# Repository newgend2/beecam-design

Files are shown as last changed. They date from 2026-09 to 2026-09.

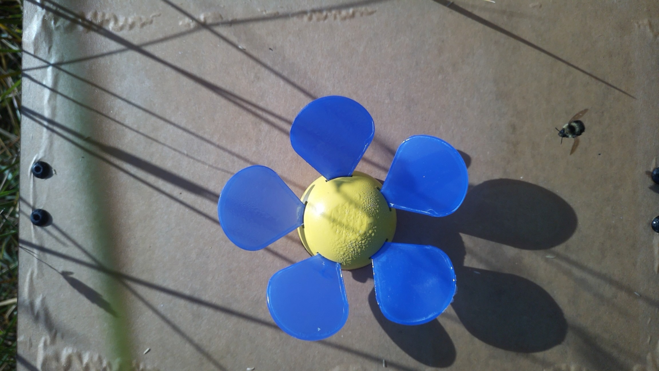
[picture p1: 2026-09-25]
docs/media/flower-prototype.jpg

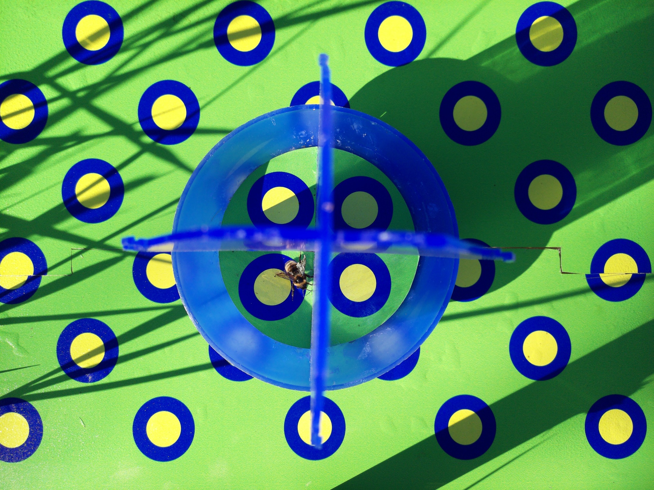
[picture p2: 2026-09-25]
docs/media/camera-visitor.jpg

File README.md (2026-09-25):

# BeeCam design

An open camera-trap assembly explorer with a labelled 3D model, dimensioned
reference drawings, custom acrylic DXFs, printable artwork and a consolidated
parts list. Explore the complete camera or the removable electronics assembly.

**[Assembly explorer](https://newgend2.github.io/beecam-design/)** ·
**[Parts list](https://newgend2.github.io/beecam-design/#materials)** ·
**[Source](https://github.com/newgend2/beecam-design)**

## Release 1.0

The frame uses six 80/20 20-2020 members: **570, 420, 280, 280, 220 and 100 mm**.
Allow saw kerf beyond the 1,870 mm net cut length. The 100 mm support sits beside
the stem with both bottoms flush; the platform crossbar rests on it. Set the
upper arm's height in the stem slot and align the camera lens over the vane.

Use four 14057 brackets, one 14060 bracket and one 20-4167 joining plate.
All black extrusion bolts are **11-5308 M5 × 8 mm**, paired with **14122 T-nuts**.
The per-camera total is **32 of each**: 22 frame, 8 platform and 2 box-to-arm.

The 420 × 300 mm imaging platform has two 3 mm acrylic panels and a Ø91.39 mm
opening for a prebuilt [BanfieldBio blue vane trap](https://www.bluevanetraps.com).
Four 3 mm acrylic stopper inserts sit between the vanes. Print the contrast
artwork on adhesive weatherproof vinyl; centre one complete bullseye on each
stopper. The trap's collection jar and lid are not installed.

The nominal 150 × 150 × 90 mm Zulkit enclosure hangs beneath the arm on a
135 × 170 × 3 mm acrylic mounting plate. The lid faces down, with hinges toward
the stem. Add two Ø22 mm lid ports, located from the internal acrylic plate,
and a centred Ø28 mm side port. Register the internal plate in the lid before
transferring the drilling datums. The enclosure includes its lid, cable gland
and four mounting screws.

## Electronics assembly

The 3 mm internal acrylic plate carries a Raspberry Pi Zero 2 W, Witty Pi 4 Mini,
full-size SparkFun DEV-14459 Qwiic HAT, SSD1306 OLED, Adafruit DS3231 STEMMA QT RTC,
CR1220 cell and Raspberry Pi AI Camera. Five Ø20 mm hook-and-loop pairs attach
the plate to the lid. Black dots are used in the build; the linked white dots
are an alternative.

Brass standoff bodies are 15 mm under the Pi, 20 mm between Pi and Witty Pi at
the end opposite the OLED, 10 mm under the OLED and 10 mm under the RTC.
The Pi and tall Witty supports have 6 mm male threads. Four 5 mm standoffs act
as retaining nuts: two at the OLED end of the Pi and two above Witty Pi.
Six M2.5 × 6 mm screws secure the Pi and RTC standoffs from under the acrylic.
Hardware comes from the HELIFOUNER 242-piece M2.5 kit and Kadrick 660-piece M2 kit.

The camera uses four M2 screws and nuts, with one M2.5 nut and one M2 washer as
spacers at each mounting point. Select M2 screw lengths for secure engagement
through each joint without bottoming out.

The Frienda 2×20 header measures **51 × 5 × 23 mm overall**, with **12 mm male
pins**, **2.54 mm pitch** and approximately **0.6 mm pin thickness**. Its sockets
fit the Pi GPIO pins; the male pins pass through the Qwiic HAT into Witty Pi.
One header is used from an eight-pack.

Two 200 mm JST SH cables connect the HAT to the RTC and OLED. Remove one connector
on the OLED cable and solder the leads left-to-right **black, red, yellow, blue**,
viewed from the screen side with the pin edge at the top. Use the AI Camera's
included 22-pin-to-15-pin ribbon to connect it to the Pi Zero. The microSD card
is 128 GB; its full-size SD adapter is shared setup equipment.

## Power and field mounting

Choose one power configuration per camera:

- **Solar:** Voltaic CORE K-P150-V102, with a 50 W panel, 12 V / 18 Ah battery,
  integrated charge controller and panel bracket. The C304 regulator supplies
  5 V to Witty Pi through USB-C.
- **Portable:** Voltaic V75 USB-A Always On output, connected to Witty Pi by a
  USB-A-to-USB-C cable. Recharge between deployments.

Runtime depends on the camera schedule and operating conditions. Attach the
camera stem to a ground-driven T-post with two locally sourced hose clamps
that fit around both members.

## Model and drawing scope

Acrylic outlines and hole positions follow the design DXFs. Inch-based source
geometry is converted at 25.4 mm/in. Use the DXFs for custom acrylic cutting and
manufacturer specifications for fit-critical checks on purchased parts.
The Witty Pi PCB and 184 component solids use UUGear’s STEP geometry; its
fitted GPIO socket and display colours are added separately. The AI Camera
follows the manufacturer physical specification, with its CSI connector facing
the plate centre. The Pi Zero 2 W follows Raspberry Pi’s mechanical drawing,
including the USB and HDMI positions; its components remain reference geometry.
The 3D model simplifies extrusion slots, castings, enclosure mouldings, other board
components and cable routing. It illustrates assembly; it is not manufacturing
CAD for purchased parts. No blue vane fabrication drawings are provided.

`docs/js/data.js` is the shared source for parts, dimensions and procurement
quantities. Generators produce the SVG drawings and CSV/Markdown downloads.
Native CAD and reference photos remain unchanged in ignored private storage.
To regenerate the Witty mesh, run `scripts/export-witty-mesh.py` with FreeCAD’s
Python and `FREECAD_LIB` set to its library directory; pass the vendor STEP path.
Web assets contain geometry-only DXFs, sanitized artwork and curated photo copies. Original CAD
notices are retained in the normalized exports.

## Field setup panel

The **Field setup** tab (`#field`) introduces the blue vane visual lure, the
earlier flower-shaped prototypes, the non-lethal adaptation, solar-powered field stations, camera images and ArUco
re-sightings. Section links and expandable questions support a short presentation.
Select a photo to enlarge it; use the arrow buttons or left/right keys to move
between photos and Escape to close. The tagged-bee crop retains its original
279 × 272 pixels. The movement example is illustrative, not a study result.

Original photographs remain in ignored private storage. Browser copies in
`docs/media/` have orientation applied and metadata removed, with no retouching
or cropping. The six reviewed copies are recorded by checksum in
`scripts/field-media-manifest.json`; the privacy audit rejects unknown or changed
raster files and metadata-bearing headers. New photo copies require the same
review before updating that manifest.

## Preview

```sh
python3 -m http.server 8767 --directory docs --bind 127.0.0.1
```

Open http://127.0.0.1:8767/. All runtime dependencies are vendored; after download,
the viewer requires no CDN, account or backend. ES modules require HTTP serving.

## Regenerate and check

```sh
# When source geometry changes (requires ezdxf):
python3 scripts/import-platform.py /path/to/source-folder
python3 scripts/import-enclosure.py /path/to/source-folder
node scripts/generate-drawings.mjs
node scripts/generate-platform-drawings.mjs
node scripts/generate-enclosure-drawings.mjs
node scripts/generate-electronics-drawings.mjs
node scripts/generate-materials.mjs
node scripts/version-assets.mjs
node scripts/version-assets.mjs --check
node tests/data-checks.mjs
node tests/enclosure-checks.mjs
node tests/electronics-checks.mjs
node tests/materials-checks.mjs
python3 scripts/audit-public.py
```

Regenerate outputs after changing the shared data. Asset versioning stamps the
entry point and application-module imports to prevent mixed cached versions.
Browser checks cover assembly selection, lid motion, isolation, drawings,
parts-list search, repository-subpath URLs and responsive layouts. The
`tests/stopper-occlusion.mjs` rendering check protects the side-view sticker fit.

Publish only `docs/` from the `main` branch using GitHub Pages. Inspect staged
files and check the complete site before publishing. Keep `private/`, original
photos, machine-specific notes and credentials out of Git.

## Sources and reuse

Product sources are linked from the viewer and parts list. The geometry source
manifest is `docs/downloads/electronics-sources.json`. Board references include
Raspberry Pi mechanical drawings, UUGear Witty Pi STEP, SparkFun DEV-14459 Eagle
files and Adafruit DS3231 Eagle/STEP files. Header dimensions come from the
[Frienda listing diagram](https://www.amazon.com/dp/B084Q4W1PW).

Original viewer code and original reference drawings use the MIT license.
Three.js 0.180.0 is vendored under its MIT license in
`docs/vendor/THREE-LICENSE.txt`. Product names, trademarks and manufacturer CAD
remain their owners'. Design geometry and artwork retain original third-party
notices; the viewer code license does not relicense commercial trap designs.

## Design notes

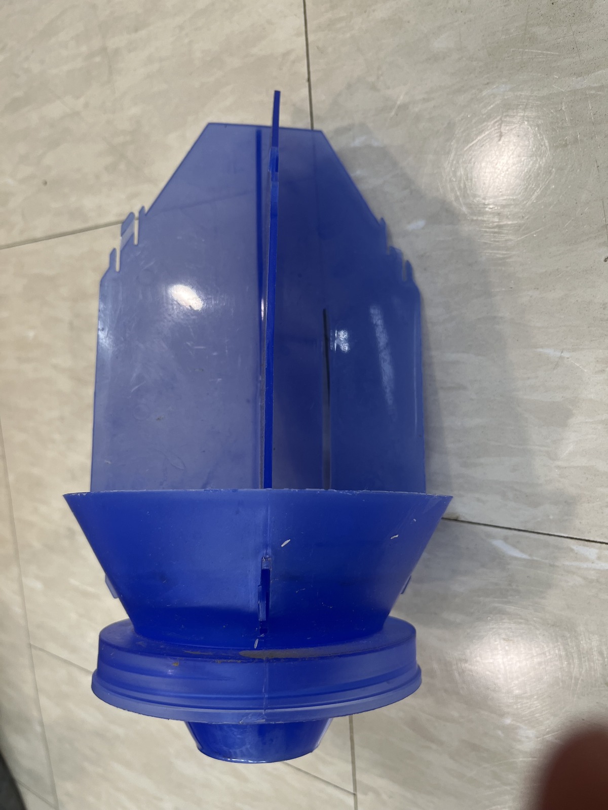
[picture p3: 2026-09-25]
docs/media/blue-vane.jpg

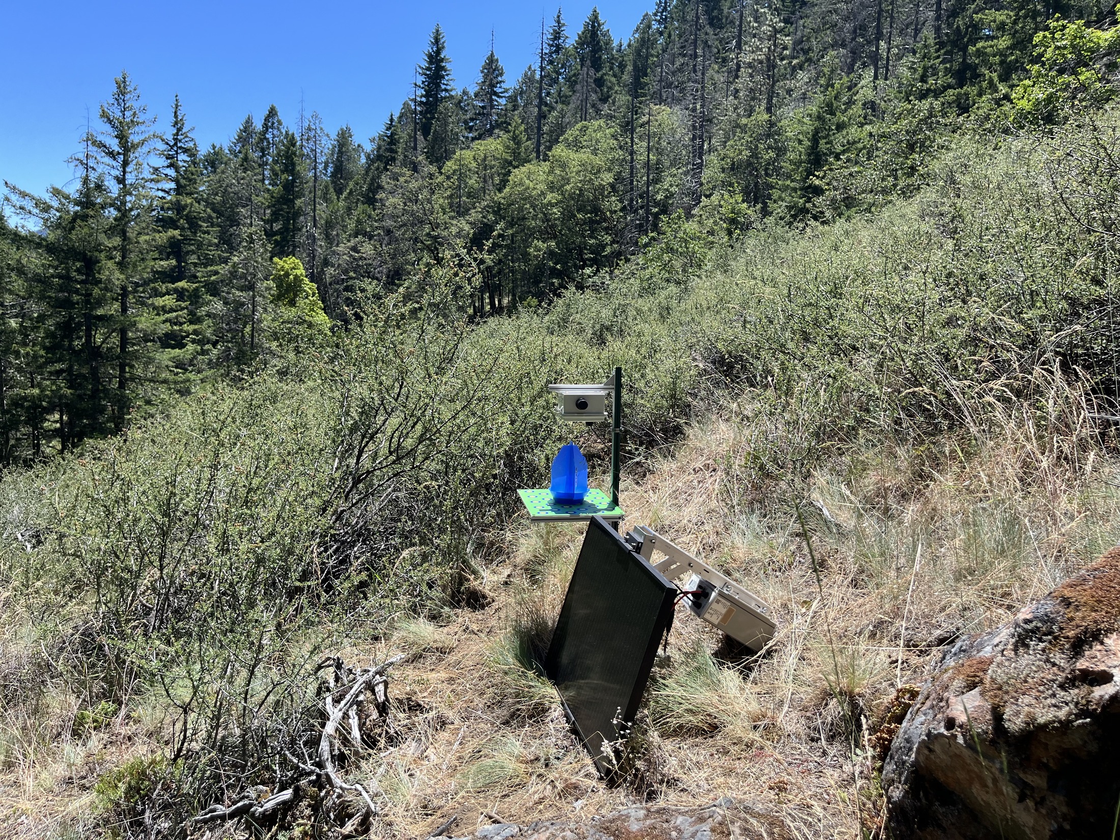
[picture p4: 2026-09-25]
docs/media/field-solar.jpg

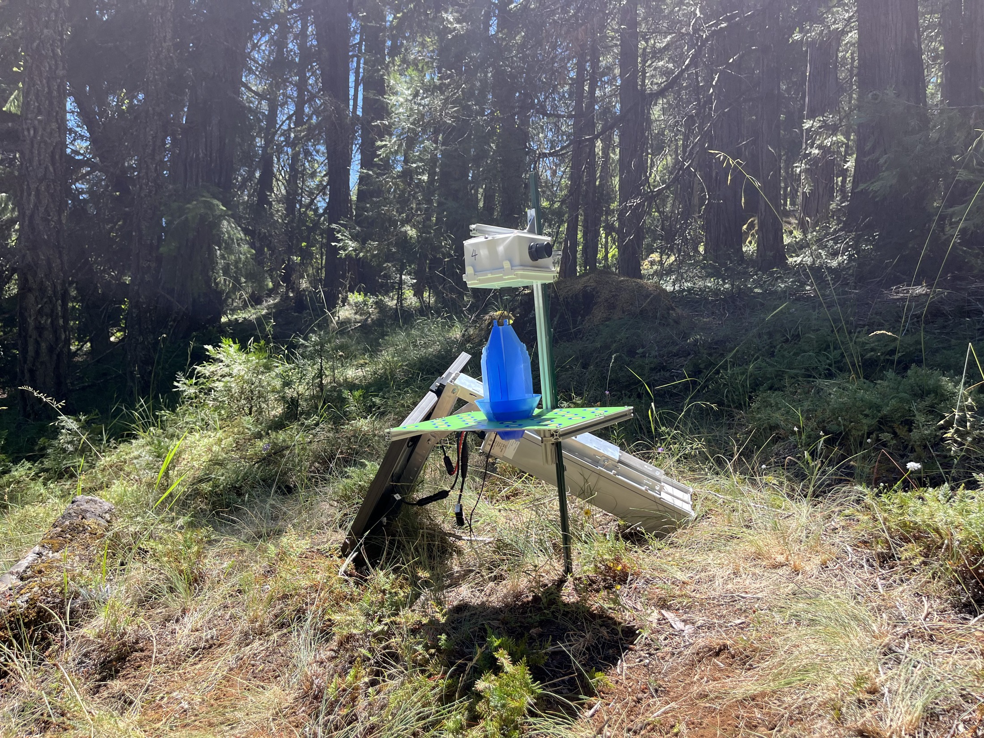
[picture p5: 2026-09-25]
docs/media/field-woodland.jpg

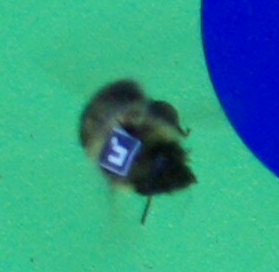
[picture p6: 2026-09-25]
docs/media/camera-aruco.png

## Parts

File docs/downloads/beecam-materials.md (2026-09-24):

# BeeCam camera-trap materials list

Release 1.0. Materials for remote monitoring of bumble bees.

Quantities are **per camera** unless marked shared, included or as needed. Kits and multipacks supply the individual pieces listed.

**80/20 total:** six 20-2020 members, 1,870 mm net; 4 × 14057, 1 × 14060, 1 × 20-4167, **32 × 11-5308 bolts and 32 × 14122 nuts**. Bolt/nut breakdown: 22 frame + 8 platform + 2 box-to-arm. Add saw kerf to raw extrusion stock.

**Cables:** two 200 mm JST SH cables, one each for RTC and OLED. The CSI ribbon is included with the AI Camera.

**Power: choose one option.** A: Voltaic CORE K-P150-V102 50 W solar / 18 Ah battery with C304 USB-C regulator. B: Voltaic V75 with a USB-A-to-USB-C cable.

## 80/20 aluminum & hardware

Per camera. Six cut members, 1,870 mm net extrusion. Allow additional stock for saw kerf. All black extrusion bolts use one part number, and all T-nuts use one part number.

| Item | Specification | Quantity | Notes | Supply |
| --- | --- | ---: | --- | --- |
| [20-2020 extrusion · vertical stem](https://8020.net/20-2020.html) | 20-2020 · 570 mm cut · 20 × 20 mm profile | 1 each |  | Per camera |
| [20-2020 extrusion · platform crossbar](https://8020.net/20-2020.html) | 20-2020 · 420 mm cut · 20 × 20 mm profile | 1 each |  | Per camera |
| [20-2020 extrusion · platform rails](https://8020.net/20-2020.html) | 20-2020 · 280 mm cut · 20 × 20 mm profile | 2 each |  | Per camera |
| [20-2020 extrusion · upper arm](https://8020.net/20-2020.html) | 20-2020 · 220 mm cut · 20 × 20 mm profile | 1 each |  | Per camera |
| [20-2020 extrusion · short support](https://8020.net/20-2020.html) | 20-2020 · 100 mm cut · 20 × 20 mm profile | 1 each |  | Per camera |
| [Supported corner bracket](https://8020.net/14057.html) | 14057 · 38 × 38 × 18 mm | 4 each | Four-hole inside corner bracket with single support. One upper-arm joint, two platform corners and one crossbar support. | Per camera |
| [Compact corner bracket](https://8020.net/14060.html) | 14060 · 18 × 18 × 18 mm | 1 each | Two-hole slotted inside corner bracket with dual support. Other crossbar support. | Per camera |
| [Square joining plate](https://8020.net/20-4167.html) | 20-4167 · 40 × 40 × 4 mm | 1 each | Joins the 100 mm support to the stem. | Per camera |
| [80/20 black button-head bolt](https://8020.net/11-5308.html) | 11-5308 · M5 × 0.8 · 8 mm long | 32 each | 11-5308 throughout: 22 frame + 8 imaging platform + 2 box-to-arm. M5 × 8 mm; all black extrusion bolts use this part. | Per camera |
| [80/20 slide-in T-nut](https://8020.net/14122.html) | 14122 · 9 × 9 × 3 mm · M5 | 32 each | 14122 throughout: one nut per 11-5308 bolt. Load from the extrusion ends. | Per camera |

## Imaging platform & prebuilt trap

Per camera. The blue vane trap is purchased prebuilt. Only the custom acrylic parts and sticker artwork need fabrication.

| Item | Specification | Quantity | Notes | Supply |
| --- | --- | ---: | --- | --- |
| Rear acrylic panel | 420 mm wide · 3 mm thick | 1 each | One rear panel from the platform design DXF. [Design file](https://newgend2.github.io/beecam-design/downloads/imaging-platform-mm.dxf) | Per camera |
| Front acrylic panel | 420 mm wide · 3 mm thick | 1 each | One front panel; the two panels form a 420 × 300 mm platform. [Design file](https://newgend2.github.io/beecam-design/downloads/imaging-platform-mm.dxf) | Per camera |
| [BanfieldBio blue vane insect trap](https://www.bluevanetraps.com) | Includes funnel/collar and crossed vanes | 1 assembly | BanfieldBio supplies cases of 24 complete traps. Use one vane/funnel assembly per camera; the collection jar and lid are not installed. | Per camera |
| Acrylic stopper inserts | R53.34 mm · 3 mm thick | 4 each | Four custom 3 mm acrylic inserts; one centred blue/yellow bullseye on each. [Design file](https://newgend2.github.io/beecam-design/downloads/vane-stopper-mm.dxf) | Per camera |
| Weatherproof vinyl contrast stickers | 420 × 300 mm sheet + insert patches | 1 set | Adhesive weatherproof vinyl: one 420 × 300 mm platform print plus four stopper patches. Platform fasteners are counted in the 80/20 section. [Design file](https://newgend2.github.io/beecam-design/assets/contrast-pattern.svg) | Per camera |

## Weatherproof box & acrylic mounts

Per camera. The lid, one lid gland and four outer-plate screws come with the enclosure. Do not purchase these a second time.

| Item | Specification | Quantity | Notes | Supply |
| --- | --- | ---: | --- | --- |
| [Zulkit hinged weatherproof enclosure](https://www.amazon.com/dp/B08KWD8TFY) | 150 × 150 × 90 mm overall | 1 each | Includes lid, gasket, supplied cable gland(s) and mounting screws. Add two Ø22 mm lid ports and one centred Ø28 mm side port. | Per camera |
| [Lid cable gland](https://www.amazon.com/dp/B08KWD8TFY) | Ø22 mm lid port | 1 included | Use one supplied gland in the lid; included with the enclosure. | Included |
| Supplied enclosure screws | Size supplied with box | 4 included | Use four supplied enclosure screws for the outer acrylic mounting plate. | Included |
| [Capped side bulkhead](https://www.amazon.com/dp/B0DHLLMRRK) | Ø28 mm wall hole · 27 mm thread | 1 each | One PATIKIL capped fitting from the linked six-pack. Fits the Ø28 mm side hole. | Per camera |
| Outer acrylic mounting plate | 135 × 170 × 3 mm | 1 each | 3 mm acrylic; four box screws plus two 11-5308/14122 pairs already counted above. [Design file](https://newgend2.github.io/beecam-design/downloads/mount-plate-mm.dxf) | Per camera |
| Internal acrylic Pi plate | 128.499 × 128.499 × 3 mm | 1 each | 3 mm acrylic, cut from the design DXF. [Design file](https://newgend2.github.io/beecam-design/downloads/internal-plate-mm.dxf) | Per camera |
| [Circular hook-and-loop pairs](https://www.amazon.com/dp/B07XHRYYXJ) | 5 pairs · Ø20 mm · black | 5 pairs | Five mating pairs = ten adhesive dots. Black in the build; the linked white Ø20 mm alternative is suitable. | Per camera |

## Electronics & installed cables

Per camera. Quantities are installed per camera, even when the purchase link is a multipack.

| Item | Specification | Quantity | Notes | Supply |
| --- | --- | ---: | --- | --- |
| [Raspberry Pi Zero 2 W with pre-soldered GPIO header](https://www.adafruit.com/product/6008) | 65 × 30 mm PCB | 1 each | Adafruit 6008; pre-soldered 40-pin header. | Per camera |
| [Raspberry Pi AI Camera](https://www.raspberrypi.com/products/ai-camera/) | 25 × 24 × 11.9 mm module | 1 each | Raspberry Pi AI Camera. | Per camera |
| [SanDisk Extreme microSDXC](https://shop.sandisk.com/products/memory-cards/microsd-cards/sandisk-extreme-uhs-i-microsd?sku=SDSQXA1-128G-GN6MA) | 128 GB · microSD | 1 each | 128 GB microSDXC UHS-I; select the package with an SD adapter. Adapter is shared setup equipment. | Per camera |
| [Witty Pi 4 Mini](https://www.uugear.com/product/witty-pi-4-mini/) | 65 × 30 mm nominal PCB | 1 each | Scheduled power management and real-time clock. | Per camera |
| [SparkFun Qwiic HAT DEV-14459](https://www.sparkfun.com/sparkfun-qwiic-hat-for-raspberry-pi.html) | 52.324 × 22.987 mm PCB | 1 each | Use full-size DEV-14459, as specified; mounts below Witty Pi on the shared GPIO pins. | Per camera |
| [Adafruit DS3231 STEMMA QT](https://www.adafruit.com/product/5188) | 25.4 × 17.78 mm PCB | 1 each | Adafruit 5188; separate precision RTC. | Per camera |
| [CR1220 backup battery](https://batteriesamerica.com/products/cr1220-5pk) | Ø12 × 2 mm · 3 V | 1 cell | One CR1220 cell installed; linked Maxell package contains five. | Per camera |
| [Hosyond SSD1306 OLED display](https://www.amazon.com/dp/B09C5K91H7) | 0.96 inch · 128 × 64 pixels | 1 each | 0.96 inch, 128 × 64, blue/yellow; one display from the linked five-pack. Board outline is schematic in the viewer. | Per camera |
| [Frienda 2×20 extra-tall stacking header](https://www.amazon.com/dp/B084Q4W1PW) | 51 × 5 × 23 mm · 2.54 mm pitch | 1 each | One Frienda header from an eight-pack. 51 × 5 × 23 mm overall; 12 mm male pins, approximately 0.6 mm thick, at 2.54 mm pitch. | Per camera |
| [JST SH 4-pin cables](https://www.adafruit.com/product/4401) | 200 mm each · 1 mm pitch | 2 each | Exactly two 200 mm cables: Qwiic HAT → RTC and Qwiic HAT → OLED. Remove one OLED-end connector; solder black/red/yellow/blue left-to-right at its pin edge. | Per camera |
| [Orange CSI camera ribbon](https://www.raspberrypi.com/products/ai-camera/) | Pi Zero camera adapter ribbon | 1 included | Included with the AI Camera package. Use its 22-pin Pi Zero to 15-pin camera ribbon. | Included |

## Small fasteners & brass standoffs

Per camera. These are individual pieces drawn from the assortment kits below. They are separate from the 80/20 hardware.

| Item | Specification | Quantity | Notes | Supply |
| --- | --- | ---: | --- | --- |
| Pi brass standoffs | 15 mm body + 6 mm male thread | 4 each | M2.5 HELIFOUNER; four 15 mm bodies with 6 mm male threads. | Per camera |
| Pi-to-Witty brass standoffs | 20 mm body + 6 mm male thread | 2 each | M2.5 HELIFOUNER; two 20 mm bodies with 6 mm male threads, opposite the OLED. | Per camera |
| 5 mm brass retaining standoffs | 5 mm body · HELIFOUNER | 4 each | Four 5 mm bodies used as nuts: two on Pi at the OLED end, two on Witty at the opposite end. | Per camera |
| OLED brass spacers | 10 mm brass spacer | 2 each | Two 10 mm brass spacers between Witty Pi and OLED. | Per camera |
| RTC brass standoffs | M2.5 · 10 mm body | 2 each | Two M2.5 brass standoffs with 10 mm bodies support the RTC. | Per camera |
| Underside M2.5 screws | M2.5 × 6 mm | 6 each | Six M2.5 × 6 mm screws from the HELIFOUNER kit: four under the Pi mounts, two under the RTC mounts. | Per camera |
| RTC upper retaining fasteners | M2.5 retaining hardware | 2 mounting points | Secure both RTC mounting holes with matching M2.5 retaining hardware from the brass standoff kit. | Per camera |
| Camera M2 screws | M2 | 4 each | Four M2 screws from the Kadrick kit. Select length to engage the nuts through the acrylic, spacers and PCB. | Per camera |
| Camera M2 nuts | M2 | 4 each | Four M2 retaining nuts, one per camera screw. | Per camera |
| Camera spacer nuts | M2.5 nuts used as spacers | 4 each | Four M2.5 nuts used as camera spacers, not as the retaining nuts. | Per camera |
| Camera spacer washers | M2 washers | 4 each | Four M2 washers, one at each camera mounting point. | Per camera |
| OLED M2 bolts | M2 | 2 each | Two M2 bolts from the Kadrick kit; select length for the PCB and 10 mm spacer assembly. | Per camera |

## Power option A · solar field setup

Choose A or B · per camera. Used in the field: Voltaic 50 W panel + 18 Ah battery → 12 V-to-5 V converter → USB-C input on Witty Pi. Power options A and B are alternatives, not cumulative requirements.

| Item | Specification | Quantity | Notes | Supply |
| --- | --- | ---: | --- | --- |
| [Voltaic CORE solar power system](https://voltaicsystems.com/50-watt-core/) | K-P150-V102 · 50 W solar panel + 12 V, 18 Ah battery | 1 kit | Includes the panel bracket and integrated battery charge controller. Select the C304 output option listed below. | Per camera |
| [Voltaic 12 V-to-5 V USB-C regulator](https://voltaicsystems.com/C304/) | C304 · M16 battery input → regulated USB-C output | 1 set | Connects the CORE battery to the Witty Pi USB-C input. Count once if supplied as the kit’s selected output option. | Per camera |

## Power option B · lighter battery setup

Choose A or B · per camera. Portable option: Voltaic V75 USB-A Always On output → USB-C cable → Witty Pi. Recharge the battery between deployments; runtime depends on the camera schedule.

| Item | Specification | Quantity | Notes | Supply |
| --- | --- | ---: | --- | --- |
| [Voltaic V75 USB battery pack](https://voltaicsystems.com/v75) | V75 · USB-A Always On output | 1 battery | Use a USB-A Always On output and USB-A-to-USB-C cable to power Witty Pi. | Per camera |
| USB-A-to-USB-C power cable | V75 USB-A → Witty Pi USB-C | 1 cable | One installed cable. Use a suitable included cable if provided; otherwise supply one separately. Choose length for the mounting arrangement. | Per camera |

## Field mounting

Per camera. Two hose clamps secure the camera stem to a T-post driven into the ground. This hardware is separate from the solar panel bracket.

| Item | Specification | Quantity | Notes | Supply |
| --- | --- | ---: | --- | --- |
| T-post | Ground-driven camera support | 1 post | Choose post length for the site and camera mounting height. | Per camera |
| Hose clamps | Clamping range to suit stem plus T-post | 2 clamps | Two standard hose clamps from a local hardware store; choose a range that fits around the stem and T-post together. | Per camera |

## Shared hardware assortments

Shared stock. Replenish individual sizes as needed. These kits supply the per-camera pieces above and are not additional installed hardware.

| Item | Specification | Quantity | Notes | Supply |
| --- | --- | ---: | --- | --- |
| [HELIFOUNER M2.5 brass standoff / screw / nut kit](https://www.amazon.com/dp/B0B7SNCFF1) | 242 pieces · M2.5 | 1 shared kit | M2.5 brass standoffs, screws and nuts. Includes M2.5 × 6 mm screws. Shared stock for the individual pieces above. | Shared |
| [Kadrick M2 screw / nut / washer kit](https://www.walmart.com/ip/3571165561) | 660 pieces | 1 shared kit | Shared stock for camera and OLED M2 screws, camera retaining nuts and washers. | Shared |

## Shared setup & data transfer

Shared equipment. Equipment for configuration and data transfer. Shared quantities are not multiplied by the number of cameras.

| Item | Specification | Quantity | Notes | Supply |
| --- | --- | ---: | --- | --- |
| Linux laptop or desktop | Ubuntu used by the lab | 1 shared | A built-in microSD slot works directly; a full-size SD slot works with the card’s adapter. | Shared |
| [USB-C microSD card reader / writer](https://www.adafruit.com/product/5212) | Adafruit 5212 · USB-C host port | 1 if needed | Only needed if the computer has no suitable card slot. | Shared |
| [Samsung T7 Shield portable SSD](https://www.samsung.com/us/computing/memory-storage/portable-solid-state-drives/portable-ssd-t7-shield-usb-3-2-2tb-black-mu-pe2t0s-am/) | 2 TB | 1 shared | Used for transferring camera data. | Shared |
| [Ethernet cable](https://www.startech.com/en-us/cables/n6patch9yl) | Cat6 · choose suitable length | 1 shared | The linked cable is 9 ft. | Shared |
| [HDMI-to-mini-HDMI cable](https://www.adafruit.com/product/2775) | Adafruit 2775 · 1.5 m example | 1 shared | For the Pi Zero mini-HDMI output during local setup. | Shared |
| [SMAYS micro-USB hub with Ethernet adapter](https://www.amazon.com/dp/B00L32UUJK) | SMAYS B00L32UUJK | 1 shared | Local setup / Ethernet connection to the Pi. | Shared |

## Shared fabrication & assembly supplies

As needed. Use existing equipment or fabrication services for cutting, drilling and wiring.

| Item | Specification | Quantity | Notes | Supply |
| --- | --- | ---: | --- | --- |
| Hex key and small screwdrivers | 3 mm hex drive for 11-5308; bits matching small screws | 1 shared set | Assembly of the extrusion and electronics hardware. | As needed |
| Extrusion and acrylic cutting / deburring | Cut six extrusion members; cut 3 mm acrylic to design DXFs | As needed service or tools | Allow saw kerf and acrylic nesting waste. Fabrication can be outsourced. | As needed |
| Enclosure drilling tools | 22 mm and 28 mm holes | 1 shared set | Two lid ports and one side port; mounting datums are documented in the drawings. | As needed |
| Soldering equipment and solder | OLED cable termination | As needed shared supplies | Includes wire stripping/cutting tools for the four soldered OLED leads. | As needed |

## Assembly reference

The blue vane trap is purchased prebuilt. Use the design DXFs for the custom acrylic panels, four stopper inserts and enclosure mounting plates. Print the contrast artwork on adhesive weatherproof vinyl. Fit the stem to a ground-driven T-post using two locally sourced hose clamps.

Select M2 screw lengths to suit each joint, with secure thread engagement and no bottoming out. Purchased component details and cable routes in the viewer are schematic; use manufacturer specifications for fit-critical checks. Set the upper-arm height in the stem slot and centre the camera lens over the vane.

Product sources checked 2026-09-24. Prices and stock are not tracked.

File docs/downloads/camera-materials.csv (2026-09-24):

category | scope | item | part_id | specification | quantity | unit | supply | notes | source | download
80/20 aluminum & hardware | Per camera | 20-2020 extrusion · vertical stem | 20-2020 | 570 mm cut · 20 × 20 mm profile | 1 | each | Per camera |  | https://8020.net/20-2020.html
80/20 aluminum & hardware | Per camera | 20-2020 extrusion · platform crossbar | 20-2020 | 420 mm cut · 20 × 20 mm profile | 1 | each | Per camera |  | https://8020.net/20-2020.html
80/20 aluminum & hardware | Per camera | 20-2020 extrusion · platform rails | 20-2020 | 280 mm cut · 20 × 20 mm profile | 2 | each | Per camera |  | https://8020.net/20-2020.html
80/20 aluminum & hardware | Per camera | 20-2020 extrusion · upper arm | 20-2020 | 220 mm cut · 20 × 20 mm profile | 1 | each | Per camera |  | https://8020.net/20-2020.html
80/20 aluminum & hardware | Per camera | 20-2020 extrusion · short support | 20-2020 | 100 mm cut · 20 × 20 mm profile | 1 | each | Per camera |  | https://8020.net/20-2020.html
80/20 aluminum & hardware | Per camera | Supported corner bracket | 14057 | 38 × 38 × 18 mm | 4 | each | Per camera | Four-hole inside corner bracket with single support. One upper-arm joint, two platform corners and one crossbar support. | https://8020.net/14057.html
80/20 aluminum & hardware | Per camera | Compact corner bracket | 14060 | 18 × 18 × 18 mm | 1 | each | Per camera | Two-hole slotted inside corner bracket with dual support. Other crossbar support. | https://8020.net/14060.html
80/20 aluminum & hardware | Per camera | Square joining plate | 20-4167 | 40 × 40 × 4 mm | 1 | each | Per camera | Joins the 100 mm support to the stem. | https://8020.net/20-4167.html
80/20 aluminum & hardware | Per camera | 80/20 black button-head bolt | 11-5308 | M5 × 0.8 · 8 mm long | 32 | each | Per camera | 11-5308 throughout: 22 frame + 8 imaging platform + 2 box-to-arm. M5 × 8 mm; all black extrusion bolts use this part. | https://8020.net/11-5308.html
80/20 aluminum & hardware | Per camera | 80/20 slide-in T-nut | 14122 | 9 × 9 × 3 mm · M5 | 32 | each | Per camera | 14122 throughout: one nut per 11-5308 bolt. Load from the extrusion ends. | https://8020.net/14122.html
Imaging platform & prebuilt trap | Per camera | Rear acrylic panel |  | 420 mm wide · 3 mm thick | 1 | each | Per camera | One rear panel from the platform design DXF. |  | downloads/imaging-platform-mm.dxf
Imaging platform & prebuilt trap | Per camera | Front acrylic panel |  | 420 mm wide · 3 mm thick | 1 | each | Per camera | One front panel; the two panels form a 420 × 300 mm platform. |  | downloads/imaging-platform-mm.dxf
Imaging platform & prebuilt trap | Per camera | BanfieldBio blue vane insect trap |  | Includes funnel/collar and crossed vanes | 1 | assembly | Per camera | BanfieldBio supplies cases of 24 complete traps. Use one vane/funnel assembly per camera; the collection jar and lid are not installed. | https://www.bluevanetraps.com
Imaging platform & prebuilt trap | Per camera | Acrylic stopper inserts |  | R53.34 mm · 3 mm thick | 4 | each | Per camera | Four custom 3 mm acrylic inserts; one centred blue/yellow bullseye on each. |  | downloads/vane-stopper-mm.dxf
Imaging platform & prebuilt trap | Per camera | Weatherproof vinyl contrast stickers |  | 420 × 300 mm sheet + insert patches | 1 | set | Per camera | Adhesive weatherproof vinyl: one 420 × 300 mm platform print plus four stopper patches. Platform fasteners are counted in the 80/20 section. |  | assets/contrast-pattern.svg
Weatherproof box & acrylic mounts | Per camera | Zulkit hinged weatherproof enclosure |  | 150 × 150 × 90 mm overall | 1 | each | Per camera | Includes lid, gasket, supplied cable gland(s) and mounting screws. Add two Ø22 mm lid ports and one centred Ø28 mm side port. | https://www.amazon.com/dp/B08KWD8TFY
Weatherproof box & acrylic mounts | Per camera | Lid cable gland |  | Ø22 mm lid port | 1 | included | Included | Use one supplied gland in the lid; included with the enclosure. | https://www.amazon.com/dp/B08KWD8TFY
Weatherproof box & acrylic mounts | Per camera | Supplied enclosure screws |  | Size supplied with box | 4 | included | Included | Use four supplied enclosure screws for the outer acrylic mounting plate.
Weatherproof box & acrylic mounts | Per camera | Capped side bulkhead |  | Ø28 mm wall hole · 27 mm thread | 1 | each | Per camera | One PATIKIL capped fitting from the linked six-pack. Fits the Ø28 mm side hole. | https://www.amazon.com/dp/B0DHLLMRRK
Weatherproof box & acrylic mounts | Per camera | Outer acrylic mounting plate |  | 135 × 170 × 3 mm | 1 | each | Per camera | 3 mm acrylic; four box screws plus two 11-5308/14122 pairs already counted above. |  | downloads/mount-plate-mm.dxf
Weatherproof box & acrylic mounts | Per camera | Internal acrylic Pi plate |  | 128.499 × 128.499 × 3 mm | 1 | each | Per camera | 3 mm acrylic, cut from the design DXF. |  | downloads/internal-plate-mm.dxf
Weatherproof box & acrylic mounts | Per camera | Circular hook-and-loop pairs |  | 5 pairs · Ø20 mm · black | 5 | pairs | Per camera | Five mating pairs = ten adhesive dots. Black in the build; the linked white Ø20 mm alternative is suitable. | https://www.amazon.com/dp/B07XHRYYXJ
Electronics & installed cables | Per camera | Raspberry Pi Zero 2 W with pre-soldered GPIO header |  | 65 × 30 mm PCB | 1 | each | Per camera | Adafruit 6008; pre-soldered 40-pin header. | https://www.adafruit.com/product/6008
Electronics & installed cables | Per camera | Raspberry Pi AI Camera |  | 25 × 24 × 11.9 mm module | 1 | each | Per camera | Raspberry Pi AI Camera. | https://www.raspberrypi.com/products/ai-camera/
Electronics & installed cables | Per camera | SanDisk Extreme microSDXC |  | 128 GB · microSD | 1 | each | Per camera | 128 GB microSDXC UHS-I; select the package with an SD adapter. Adapter is shared setup equipment. | https://shop.sandisk.com/products/memory-cards/microsd-cards/sandisk-extreme-uhs-i-microsd?sku=SDSQXA1-128G-GN6MA
Electronics & installed cables | Per camera | Witty Pi 4 Mini |  | 65 × 30 mm nominal PCB | 1 | each | Per camera | Scheduled power management and real-time clock. | https://www.uugear.com/product/witty-pi-4-mini/
Electronics & installed cables | Per camera | SparkFun Qwiic HAT DEV-14459 |  | 52.324 × 22.987 mm PCB | 1 | each | Per camera | Use full-size DEV-14459, as specified; mounts below Witty Pi on the shared GPIO pins. | https://www.sparkfun.com/sparkfun-qwiic-hat-for-raspberry-pi.html
Electronics & installed cables | Per camera | Adafruit DS3231 STEMMA QT |  | 25.4 × 17.78 mm PCB | 1 | each | Per camera | Adafruit 5188; separate precision RTC. | https://www.adafruit.com/product/5188
Electronics & installed cables | Per camera | CR1220 backup battery |  | Ø12 × 2 mm · 3 V | 1 | cell | Per camera | One CR1220 cell installed; linked Maxell package contains five. | https://batteriesamerica.com/products/cr1220-5pk
Electronics & installed cables | Per camera | Hosyond SSD1306 OLED display |  | 0.96 inch · 128 × 64 pixels | 1 | each | Per camera | 0.96 inch, 128 × 64, blue/yellow; one display from the linked five-pack. Board outline is schematic in the viewer. | https://www.amazon.com/dp/B09C5K91H7
Electronics & installed cables | Per camera | Frienda 2×20 extra-tall stacking header |  | 51 × 5 × 23 mm · 2.54 mm pitch | 1 | each | Per camera | One Frienda header from an eight-pack. 51 × 5 × 23 mm overall; 12 mm male pins, approximately 0.6 mm thick, at 2.54 mm pitch. | https://www.amazon.com/dp/B084Q4W1PW
Electronics & installed cables | Per camera | JST SH 4-pin cables |  | 200 mm each · 1 mm pitch | 2 | each | Per camera | Exactly two 200 mm cables: Qwiic HAT → RTC and Qwiic HAT → OLED. Remove one OLED-end connector; solder black/red/yellow/blue left-to-right at its pin edge. | https://www.adafruit.com/product/4401
Electronics & installed cables | Per camera | Orange CSI camera ribbon |  | Pi Zero camera adapter ribbon | 1 | included | Included | Included with the AI Camera package. Use its 22-pin Pi Zero to 15-pin camera ribbon. | https://www.raspberrypi.com/products/ai-camera/
Small fasteners & brass standoffs | Per camera | Pi brass standoffs |  | 15 mm body + 6 mm male thread | 4 | each | Per camera | M2.5 HELIFOUNER; four 15 mm bodies with 6 mm male threads.
Small fasteners & brass standoffs | Per camera | Pi-to-Witty brass standoffs |  | 20 mm body + 6 mm male thread | 2 | each | Per camera | M2.5 HELIFOUNER; two 20 mm bodies with 6 mm male threads, opposite the OLED.
Small fasteners & brass standoffs | Per camera | 5 mm brass retaining standoffs |  | 5 mm body · HELIFOUNER | 4 | each | Per camera | Four 5 mm bodies used as nuts: two on Pi at the OLED end, two on Witty at the opposite end.
Small fasteners & brass standoffs | Per camera | OLED brass spacers |  | 10 mm brass spacer | 2 | each | Per camera | Two 10 mm brass spacers between Witty Pi and OLED.
Small fasteners & brass standoffs | Per camera | RTC brass standoffs |  | M2.5 · 10 mm body | 2 | each | Per camera | Two M2.5 brass standoffs with 10 mm bodies support the RTC.
Small fasteners & brass standoffs | Per camera | Underside M2.5 screws |  | M2.5 × 6 mm | 6 | each | Per camera | Six M2.5 × 6 mm screws from the HELIFOUNER kit: four under the Pi mounts, two under the RTC mounts.
Small fasteners & brass standoffs | Per camera | RTC upper retaining fasteners |  | M2.5 retaining hardware | 2 | mounting points | Per camera | Secure both RTC mounting holes with matching M2.5 retaining hardware from the brass standoff kit.
Small fasteners & brass standoffs | Per camera | Camera M2 screws |  | M2 | 4 | each | Per camera | Four M2 screws from the Kadrick kit. Select length to engage the nuts through the acrylic, spacers and PCB.
Small fasteners & brass standoffs | Per camera | Camera M2 nuts |  | M2 | 4 | each | Per camera | Four M2 retaining nuts, one per camera screw.
Small fasteners & brass standoffs | Per camera | Camera spacer nuts |  | M2.5 nuts used as spacers | 4 | each | Per camera | Four M2.5 nuts used as camera spacers, not as the retaining nuts.
Small fasteners & brass standoffs | Per camera | Camera spacer washers |  | M2 washers | 4 | each | Per camera | Four M2 washers, one at each camera mounting point.
Small fasteners & brass standoffs | Per camera | OLED M2 bolts |  | M2 | 2 | each | Per camera | Two M2 bolts from the Kadrick kit; select length for the PCB and 10 mm spacer assembly.
Power option A · solar field setup | Choose A or B · per camera | Voltaic CORE solar power system | K-P150-V102 | 50 W solar panel + 12 V, 18 Ah battery | 1 | kit | Per camera | Includes the panel bracket and integrated battery charge controller. Select the C304 output option listed below. | https://voltaicsystems.com/50-watt-core/
Power option A · solar field setup | Choose A or B · per camera | Voltaic 12 V-to-5 V USB-C regulator | C304 | M16 battery input → regulated USB-C output | 1 | set | Per camera | Connects the CORE battery to the Witty Pi USB-C input. Count once if supplied as the kit’s selected output option. | https://voltaicsystems.com/C304/
Power option B · lighter battery setup | Choose A or B · per camera | Voltaic V75 USB battery pack |  | V75 · USB-A Always On output | 1 | battery | Per camera | Use a USB-A Always On output and USB-A-to-USB-C cable to power Witty Pi. | https://voltaicsystems.com/v75
Power option B · lighter battery setup | Choose A or B · per camera | USB-A-to-USB-C power cable |  | V75 USB-A → Witty Pi USB-C | 1 | cable | Per camera | One installed cable. Use a suitable included cable if provided; otherwise supply one separately. Choose length for the mounting arrangement.
Field mounting | Per camera | T-post |  | Ground-driven camera support | 1 | post | Per camera | Choose post length for the site and camera mounting height.
Field mounting | Per camera | Hose clamps |  | Clamping range to suit stem plus T-post | 2 | clamps | Per camera | Two standard hose clamps from a local hardware store; choose a range that fits around the stem and T-post together.
Shared hardware assortments | Shared stock | HELIFOUNER M2.5 brass standoff / screw / nut kit |  | 242 pieces · M2.5 | 1 | shared kit | Shared | M2.5 brass standoffs, screws and nuts. Includes M2.5 × 6 mm screws. Shared stock for the individual pieces above. | https://www.amazon.com/dp/B0B7SNCFF1
Shared hardware assortments | Shared stock | Kadrick M2 screw / nut / washer kit |  | 660 pieces | 1 | shared kit | Shared | Shared stock for camera and OLED M2 screws, camera retaining nuts and washers. | https://www.walmart.com/ip/3571165561
Shared setup & data transfer | Shared equipment | Linux laptop or desktop |  | Ubuntu used by the lab | 1 | shared | Shared | A built-in microSD slot works directly; a full-size SD slot works with the card’s adapter.
Shared setup & data transfer | Shared equipment | USB-C microSD card reader / writer |  | Adafruit 5212 · USB-C host port | 1 | if needed | Shared | Only needed if the computer has no suitable card slot. | https://www.adafruit.com/product/5212
Shared setup & data transfer | Shared equipment | Samsung T7 Shield portable SSD |  | 2 TB | 1 | shared | Shared | Used for transferring camera data. | https://www.samsung.com/us/computing/memory-storage/portable-solid-state-drives/portable-ssd-t7-shield-usb-3-2-2tb-black-mu-pe2t0s-am/
Shared setup & data transfer | Shared equipment | Ethernet cable |  | Cat6 · choose suitable length | 1 | shared | Shared | The linked cable is 9 ft. | https://www.startech.com/en-us/cables/n6patch9yl
Shared setup & data transfer | Shared equipment | HDMI-to-mini-HDMI cable |  | Adafruit 2775 · 1.5 m example | 1 | shared | Shared | For the Pi Zero mini-HDMI output during local setup. | https://www.adafruit.com/product/2775
Shared setup & data transfer | Shared equipment | SMAYS micro-USB hub with Ethernet adapter |  | SMAYS B00L32UUJK | 1 | shared | Shared | Local setup / Ethernet connection to the Pi. | https://www.amazon.com/dp/B00L32UUJK
Shared fabrication & assembly supplies | As needed | Hex key and small screwdrivers |  | 3 mm hex drive for 11-5308; bits matching small screws | 1 | shared set | As needed | Assembly of the extrusion and electronics hardware.
Shared fabrication & assembly supplies | As needed | Extrusion and acrylic cutting / deburring |  | Cut six extrusion members; cut 3 mm acrylic to design DXFs | As needed | service or tools | As needed | Allow saw kerf and acrylic nesting waste. Fabrication can be outsourced.
Shared fabrication & assembly supplies | As needed | Enclosure drilling tools |  | 22 mm and 28 mm holes | 1 | shared set | As needed | Two lid ports and one side port; mounting datums are documented in the drawings.
Shared fabrication & assembly supplies | As needed | Soldering equipment and solder |  | OLED cable termination | As needed | shared supplies | As needed | Includes wire stripping/cutting tools for the four soldered OLED leads.

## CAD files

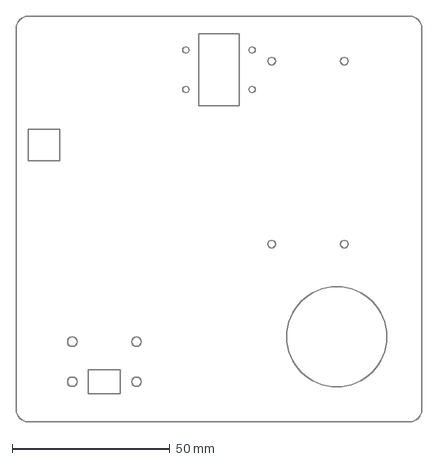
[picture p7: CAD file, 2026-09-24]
docs/downloads/internal-plate-mm.dxf
128.5 x 128.5 mm

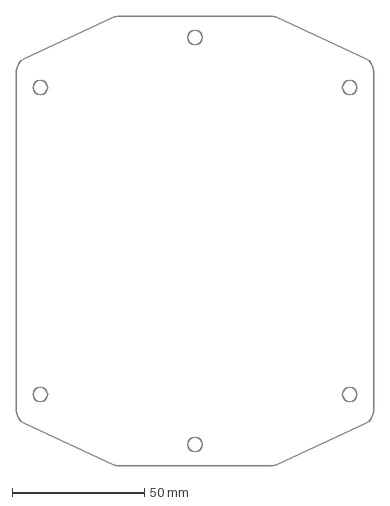
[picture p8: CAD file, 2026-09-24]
docs/downloads/mount-plate-mm.dxf
135.0 x 170.0 mm

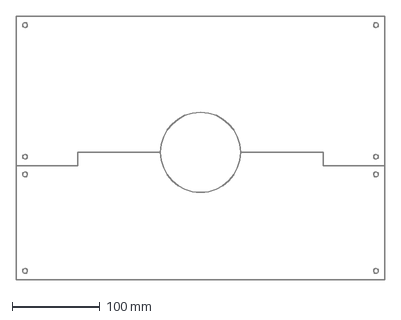
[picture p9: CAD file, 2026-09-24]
docs/downloads/imaging-platform-mm.dxf
420.0 x 300.0 mm

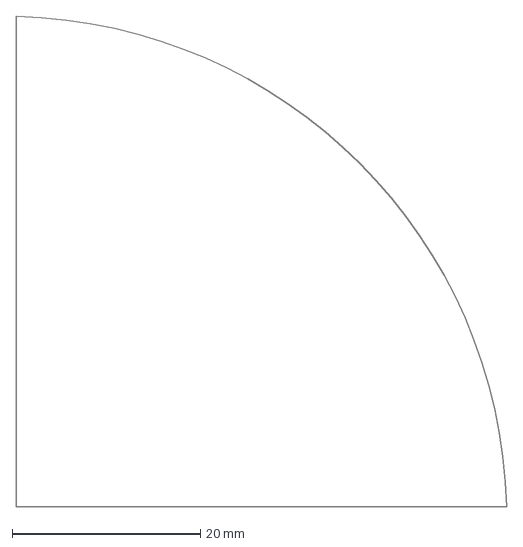
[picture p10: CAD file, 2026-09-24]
docs/downloads/vane-stopper-mm.dxf
52.1 x 52.1 mm

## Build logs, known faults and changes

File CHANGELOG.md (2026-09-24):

# Changelog

## 1.0 — 2026-09-24

- Added a consolidated parts-list tab with supplier links, per-camera quantities,
  shared equipment, included parts, CSV/Markdown downloads, search and printing.
- Standardized extrusion hardware to 32 each of 80/20 11-5308 bolts and 14122 nuts.
- Documented solar and portable power options, T-post mounting, weatherproof vinyl,
  four acrylic stopper inserts, included camera ribbon and hardware assortments.
- Added catalogue dimensions for the Frienda stacking header and 10 mm RTC supports.
- Replaced development-review copy with assembly and purchasing guidance.
- Retained custom acrylic drawings while treating the blue vane trap as a prebuilt component.

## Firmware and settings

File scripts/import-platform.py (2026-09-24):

"""Extract only explicit geometry and drawing units from the supplied CAD files.

Raw originals are archived privately. Public DXFs are new, geometry-only exports
with millimetre coordinates and no author, application, path or machine metadata.
"""
from pathlib import Path
from collections import Counter
import argparse, hashlib, json, math, shutil, xml.etree.ElementTree as ET

ROOT = Path(__file__).resolve().parents[1]
parser = argparse.ArgumentParser()
parser.add_argument('source_dir', type=Path)
args = parser.parse_args()
private = ROOT / 'private' / 'platform-sources'
private.mkdir(parents=True, exist_ok=True)
public = ROOT / 'docs' / 'downloads'
public.mkdir(exist_ok=True)
assets = ROOT / 'docs' / 'assets'
assets.mkdir(exist_ok=True)
names = ['imaging_platform_420x300mm_91.39mmdiameter.DXF', 'vane_stopper.dxf',
         'contrast_mm_42_30.svg', 'cambox_plate_v2.DXF']
manifest = []
for name in names:
    source = args.source_dir / name
    dest = private / name
    data = source.read_bytes()
    if dest.exists() and dest.read_bytes() != data:
        raise ValueError(f'Private source already exists with different bytes: {name}')
    if not dest.exists():
        shutil.copyfile(source, dest)
    manifest.append({'source': str(source), 'archive': name, 'sha256': hashlib.sha256(data).hexdigest()})
(private / 'manifest.json').write_text(json.dumps(manifest, indent=2) + '\n')

def read_dxf(path):
    lines = path.read_text().splitlines()
    pairs = [(int(lines[i].strip()), lines[i+1].strip()) for i in range(0, len(lines), 2)]
    units = next(int(pairs[i+1][1]) for i,p in enumerate(pairs) if p == (9, '$INSUNITS'))
    entities, current, inside = [], None, False
    for code, value in pairs:
        if (code,value) == (2,'ENTITIES'):
            inside = True
            continue
        if not inside:
            continue
        if code == 0:
            if current:
                entities.append(current)
            if value == 'ENDSEC':
                break
            current = {'type':value, 'groups':[]}
        elif current:
            current['groups'].append((code,value))
    return units, entities

def val(e, code, default=None):
    return next((float(v) for c,v in e['groups'] if c == code), default)

units, entities = read_dxf(private / names[0])
assert units == 4, 'Platform source must use millimetres'
lines = [e for e in entities if e['type'] == 'LINE']
circles = [e for e in entities if e['type'] == 'CIRCLE']
assert len(lines) == 10 and len(circles) == 9
minx = min(val(e,c) for e in lines for c in [10,11])
miny = min(val(e,c) for e in lines for c in [20,21])
maxx = max(val(e,c) for e in lines for c in [10,11])
maxy = max(val(e,c) for e in lines for c in [20,21])
assert math.isclose(maxx-minx,420) and math.isclose(maxy-miny,300)
norm = lambda x,y: [round(x-minx,9), round(y-miny,9)]
outlines = [{'a':norm(val(e,10),val(e,20)), 'b':norm(val(e,11),val(e,21))} for e in lines]
holes = [{'center':norm(val(e,10),val(e,20)), 'radius':round(val(e,40),9)} for e in circles]
opening = max(holes, key=lambda h:h['radius'])
bolt_holes = sorted([h for h in holes if h != opening], key=lambda h:h['center'])
assert opening == {'center':[210.0,145.0], 'radius':45.695}
assert all(math.isclose(h['radius'],2.75) for h in bolt_holes)
assert sorted(set(round(p[1],6) for l in outlines for p in [l['a'],l['b']])) == [0,130,145,300]

units, stopper_entities = read_dxf(private / names[1])
assert units == 1, 'Stopper source must use inches'
vertices = [e for e in stopper_entities if e['type'] == 'VERTEX']
assert len(vertices) == 3
verts = [{'point':[val(e,10)*25.4,val(e,20)*25.4], 'bulge':val(e,42,0)} for e in vertices]
p1,p2 = verts[2]['point'],verts[0]['point']
bulge = verts[2]['bulge']; chord = math.dist(p1,p2)
radius = chord*(1+bulge**2)/(4*bulge)
distance = chord*(1-bulge**2)/(4*bulge)
cx = (p1[0]+p2[0])/2-distance*(p2[1]-p1[1])/chord
cy = (p1[1]+p2[1])/2+distance*(p2[0]-p1[0])/chord
assert math.isclose(radius,53.34) and abs(cx)<1e-8 and abs(cy)<1e-8

geometry = {'units':'mm', 'platform':{'size':[420,300], 'opening':opening,
    'boltHoles':bolt_holes, 'cutLines':outlines, 'sourceUnits':'mm'},
    'stopper':{'vertices':verts, 'arcRadius':round(radius,9), 'arcCenter':[round(cx,9),round(cy,9)],
    'arcSweepDegrees':4*math.atan(bulge)*180/math.pi,'sourceUnits':'inch','conversion':25.4,
    'clearanceFromVaneCenter':1.27, 'straightEdge':p1[0]-1.27}}
(public / 'platform-geometry.json').write_text(json.dumps(geometry, indent=2)+'\n')
(ROOT/'docs'/'js'/'platform-geometry.js').write_text('// Extracted from supplied DXF geometry by scripts/import-platform.py.\nexport default '+json.dumps(geometry,indent=2)+';\n')

def write_dxf(name, parts, notice=None):
    pairs = [(0,'SECTION'),(2,'HEADER'),(9,'$ACADVER'),(1,'AC1015'),(9,'$INSUNITS'),(70,4),
             (9,'$MEASUREMENT'),(70,1),(0,'ENDSEC'),(0,'SECTION'),(2,'ENTITIES')]
    if notice:
        pairs.append((999,notice))
    pairs.extend(parts)
    pairs += [(0,'ENDSEC'),(0,'EOF')]
    (public/name).write_text(''.join(f'{c}\n{v:.12g}\n' if isinstance(v,float) else f'{c}\n{v}\n' for c,v in pairs))

output=[]
for l in outlines:
    output += [(0,'LINE'),(100,'AcDbEntity'),(8,'CUT'),(100,'AcDbLine'),(10,l['a'][0]),(20,l['a'][1]),(30,0),
               (11,l['b'][0]),(21,l['b'][1]),(31,0)]
for h in holes:
    output += [(0,'CIRCLE'),(100,'AcDbEntity'),(8,'CUT'),(100,'AcDbCircle'),(10,h['center'][0]),(20,h['center'][1]),(30,0),(40,h['radius'])]
write_dxf('imaging-platform-mm.dxf',output,
          'Source drawing notice: SOLIDWORKS Educational Product. For Instructional Use Only.')
output=[(0,'LWPOLYLINE'),(100,'AcDbEntity'),(8,'CUT'),(100,'AcDbPolyline'),(90,3),(70,1)]
for vert in verts:
    output += [(10,vert['point'][0]),(20,vert['point'][1]),(42,vert['bulge'])]
write_dxf('vane-stopper-mm.dxf',output)

# Retain the actual vector artwork and all clipping. Strip editor-only metadata.
SVG='http://www.w3.org/2000/svg'
ET.register_namespace('',SVG)
original=ET.parse(private/names[2]).getroot()
allowed_tags={'svg','g','defs','clipPath','rect','circle'}
allowed_attrs={'width','height','viewBox','version','id','style','x','y','rx','ry','cx','cy','r',
               'transform','clip-path','clipPathUnits','fill','stroke','stroke-width'}
def clean(el):
    if el.tag.split('}')[-1] not in allowed_tags:
        return None
    new=ET.Element(el.tag,{k:v for k,v in el.attrib.items() if k in allowed_attrs})
    for child in el:
        result=clean(child)
        if result is not None:
            new.append(result)
    return new
sanitized=clean(original)
assert sanitized.attrib['width']=='420mm' and sanitized.attrib['height']=='300mm'
ET.ElementTree(sanitized).write(assets/'contrast-pattern.svg',encoding='utf-8',xml_declaration=True)
print('Imported 420 × 300 platform, Ø91.39 opening, eight Ø5.5 holes, R53.34 stopper and exact sticker artwork.')

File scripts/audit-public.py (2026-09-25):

"""Audit the public artifact, including SVG metadata, links and hosting size."""
from pathlib import Path
import hashlib
import json
import re
import struct
import xml.etree.ElementTree as ET
root = Path(__file__).resolve().parents[1]
public = root / 'docs'
problems = []
total = 0
media_manifest = json.loads((root / 'scripts/field-media-manifest.json').read_text())
seen_media = set()

def clean_raster(data, suffix):
    """Allow only image data and essential format headers, with no photo metadata."""
    if suffix == '.png':
        if not data.startswith(b'\x89PNG\r\n\x1a\n'):
            return False
        pos = 8
        while pos + 12 <= len(data):
            length = struct.unpack('>I', data[pos:pos+4])[0]
            kind = data[pos+4:pos+8]
            if kind not in {b'IHDR', b'PLTE', b'IDAT', b'IEND', b'tRNS'}:
                return False
            pos += length + 12
            if kind == b'IEND':
                return pos == len(data)
        return False
    if suffix in {'.jpg', '.jpeg'} and data.startswith(b'\xff\xd8'):
        pos = 2
        while pos + 4 <= len(data):
            if data[pos] != 0xff:
                return False
            marker = data[pos+1]
            # APP1-APP15 / COM can carry EXIF, XMP, IPTC or comments. Only JFIF is allowed.
            if marker in range(0xe1, 0xf0) or marker == 0xfe:
                return False
            if marker == 0xda:
                return data.endswith(b'\xff\xd9')
            length = struct.unpack('>H', data[pos+2:pos+4])[0]
            if length < 2:
                return False
            pos += length + 2
        return False
    return False

for p in public.rglob('*'):
    if not p.is_file():
        continue
    total += p.stat().st_size
    relative = p.relative_to(public)
    if p.suffix.lower() in {'.jpg', '.jpeg', '.png', '.heic', '.webp'}:
        name = relative.as_posix()
        expected = media_manifest.get(name)
        data = p.read_bytes()
        if not expected or hashlib.sha256(data).hexdigest() != expected['sha256']:
            problems.append(f'Raster asset missing from reviewed media manifest or changed: {relative}')
        if not clean_raster(data, p.suffix.lower()):
            problems.append(f'Raster contains metadata or unsupported format: {relative}')
        seen_media.add(name)
        continue
    text = p.read_text(errors='replace')
    for pattern in [r'/Users/', r'/private/var/', r'file://', r'gh[pousr]_[A-Za-z0-9]{20,}', r'-----BEGIN .*PRIVATE KEY', r'localhost', r'127\.0\.0\.1']:
        if re.search(pattern, text):
            problems.append(f'Private/local content: {relative}: {pattern}')
    if p.suffix == '.svg':
        doc = ET.fromstring(text)
        if any(x.tag.split('}')[-1] in {'metadata', 'script', 'image'} for x in doc.iter()):
            problems.append(f'Embedded metadata or executable/remote content: {relative}')
    if p.suffix == '.html':
        for link in re.findall(r'(?:src|href)="([^"]+)"', text):
            if link.startswith(('https:', 'data:', '#')):
                continue
            if not (p.parent / link.split('#')[0].split('?')[0]).exists():
                problems.append(f'Missing local link: {relative}: {link}')
for missing in media_manifest.keys() - seen_media:
    problems.append(f'Missing reviewed image: {missing}')
if total >= 1_000_000_000:
    problems.append('Site exceeds 1 GB hosting budget')
if problems:
    raise SystemExit('\n'.join(problems))
print(f'PASS: {len(list(public.rglob("*")))} entries; {total:,} bytes; no private paths, credentials, photo metadata or broken static HTML links.')

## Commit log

2026-09-24 Build interactive BeeCam frame explorer with dimensioned drawings and materials
    [frame-materials.csv]
2026-09-24 Add CAD-based imaging platform, cone, drawings and materials
    [camera-materials.csv, imaging-platform-mm.dxf, vane-cone-mm.stl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]
2026-09-24 Refine vane proportions from photo and center stopper bullseyes
    [camera-materials.csv]
2026-09-24 Add weatherproof enclosure, opening lid and camera assembly
    [camera-materials.csv, internal-plate-mm.dxf, mount-plate-mm.dxf]
2026-09-24 Reverse enclosure hinges and refresh cached viewer assets
    [camera-materials.csv]
2026-09-24 Add lid-mounted electronics stack and wiring documentation
    [camera-materials.csv]
2026-09-24 Prepare BeeCam 1.0 assembly and materials release
    [camera-materials.csv, frame-materials.csv, vane-cone-mm.stl]
2026-09-25 Correct electronics models and publish field guide
    [audit-public.py]
